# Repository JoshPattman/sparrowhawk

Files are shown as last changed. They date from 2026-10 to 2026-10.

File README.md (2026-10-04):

# Sparrowhawk

A sub-250g RC flying wing that is as quick to build as possible: two 3D printed parts for the fuselage, and one simple shape cut from foamboard for the wing.

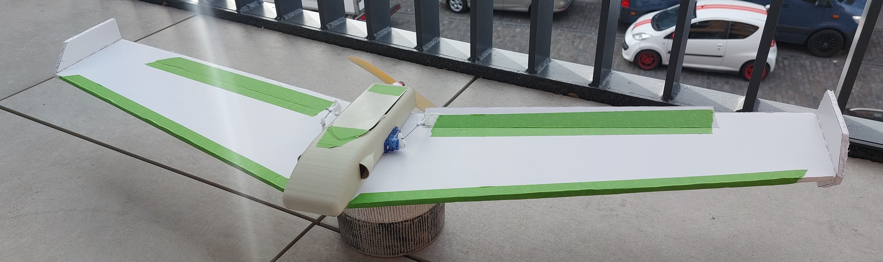
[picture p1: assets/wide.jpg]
Sparrowhawk


Sparrowhawk is designed to maximise wingspan, build speed, and robustness while staying under 250g.

- **Wingspan:** 841mm (the full width of an A1 sheet)
- **All-up weight:** 242g as built, including a 3S 850mAh battery
- **Flight time:** 15-20 minutes on a 3S 850mAh battery
- **Aerobatics:** flips and rolls with ease
- **Build:** two printed parts and one sheet of A1 foamboard, which is enough for two wings

## Plans

The plans include the full parts list, the foamboard cutting template for the wing and wingtips, and the CG position. All dimensions are in mm, and the sheet is A1.

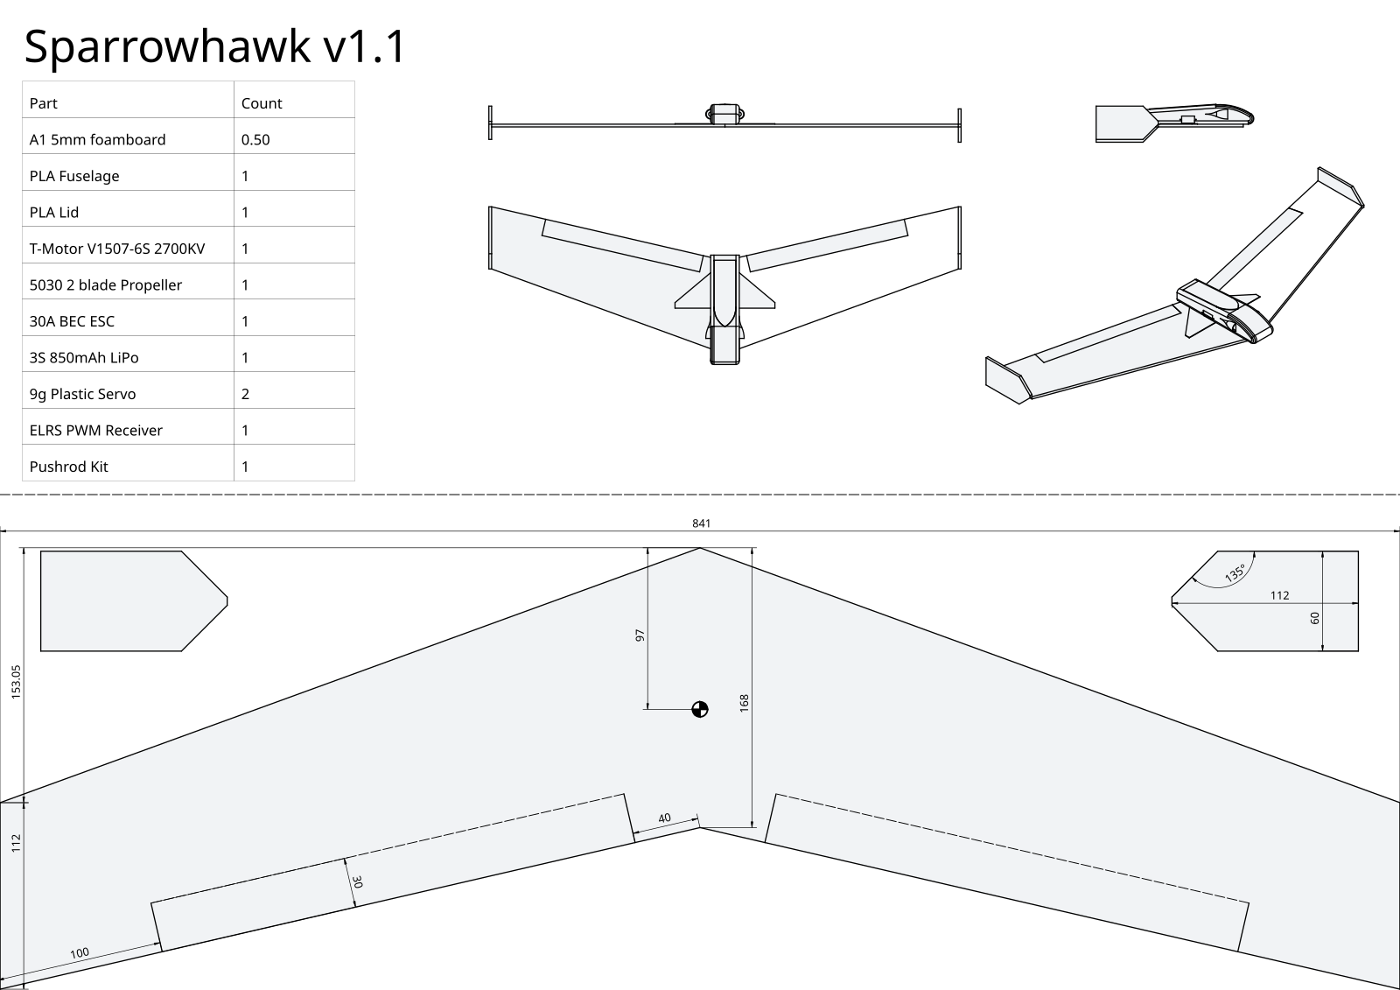
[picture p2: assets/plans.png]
Plans


The full-size A1 plans are in [`plans/sparrowhawk_Plans.svg`](plans/sparrowhawk_Plans.svg).

## Build

1. Print the [fuselage](stl/sparrowhawk-Fuselage.stl) and [lid](stl/sparrowhawk-Lid.stl).
2. Cut one wing and two wingtips from foamboard using the plans.
3. Cut the elevons free and hinge them back on with tape (also leave a layer of paper and bevel them).
4. Attach the wingtips to the ends of the wing with glue gun.
5. Fit the motor, ESC, receiver, and servos into the fuselage, then attach the fuselage to the wing.
6. Connect the servos to the elevons with the pushrods and control horns.
7. Set up elevon mixing on your transmitter.

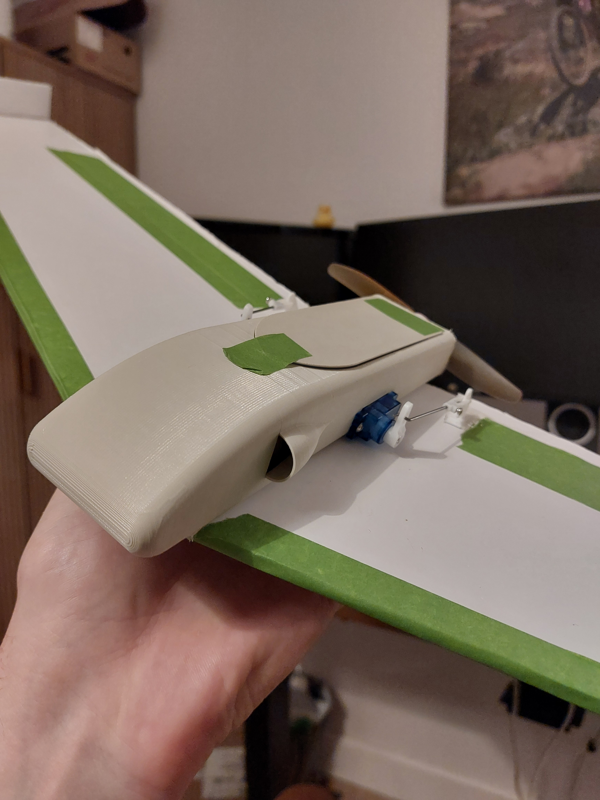
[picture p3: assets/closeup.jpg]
Close-up of the fuselage and servo linkage


## CAD

The full model is in [`sparrowhawk.FCStd`](sparrowhawk.FCStd), which opens in [FreeCAD](https://www.freecad.org/).

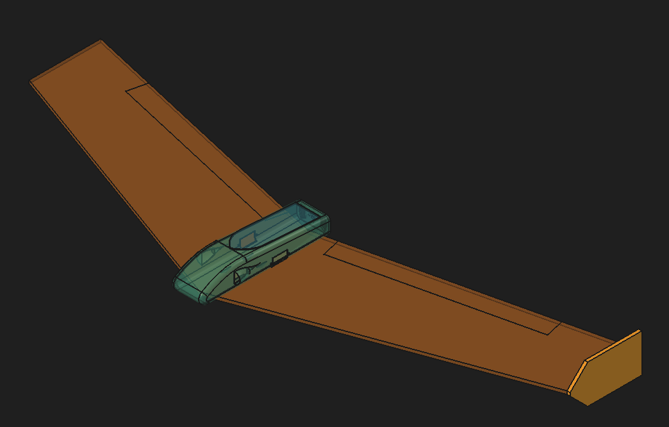
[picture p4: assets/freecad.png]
FreeCAD model


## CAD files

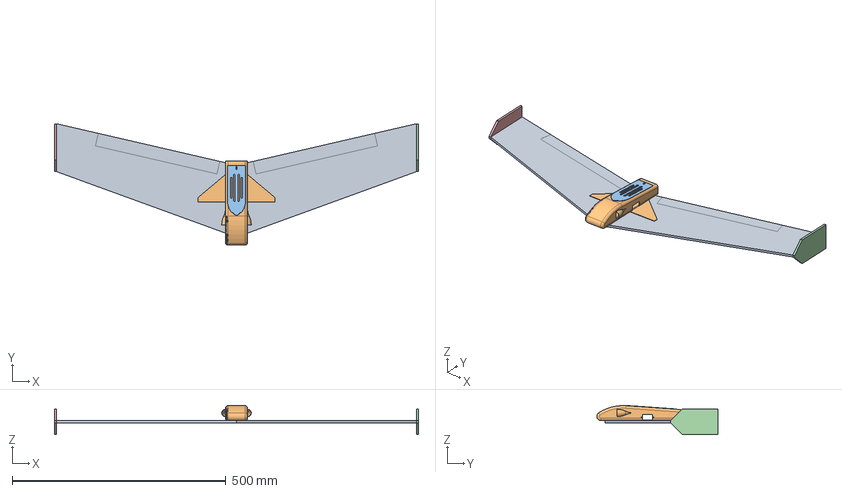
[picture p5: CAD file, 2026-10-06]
sparrowhawk.FCStd
851.0 x 284.0 x 68.1 mm
Wing
Fuselage
Lid
Wingtip
OtherWingtip
Latch

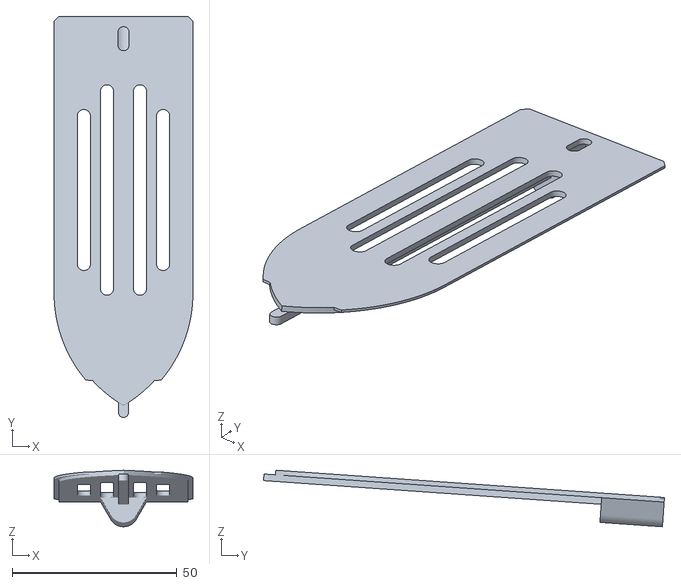
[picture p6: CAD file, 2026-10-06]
stl/sparrowhawk-Lid.stl
42.1 x 121.5 x 17.1

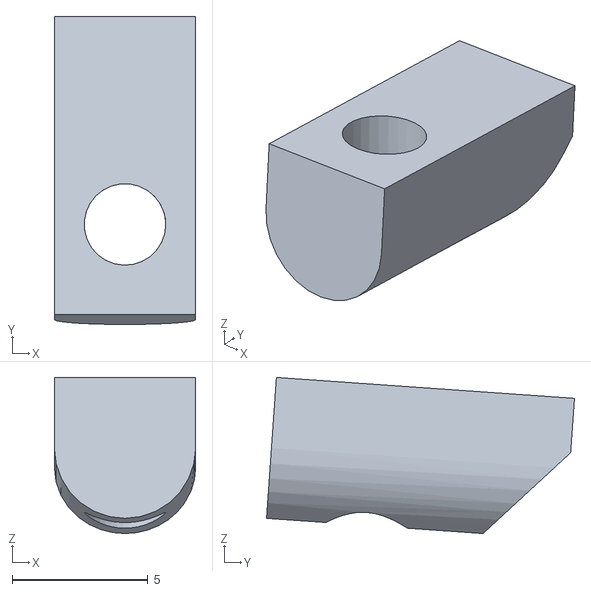
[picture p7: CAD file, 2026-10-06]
stl/sparrowhawk-Latch.stl
5.20 x 11.3 x 5.75

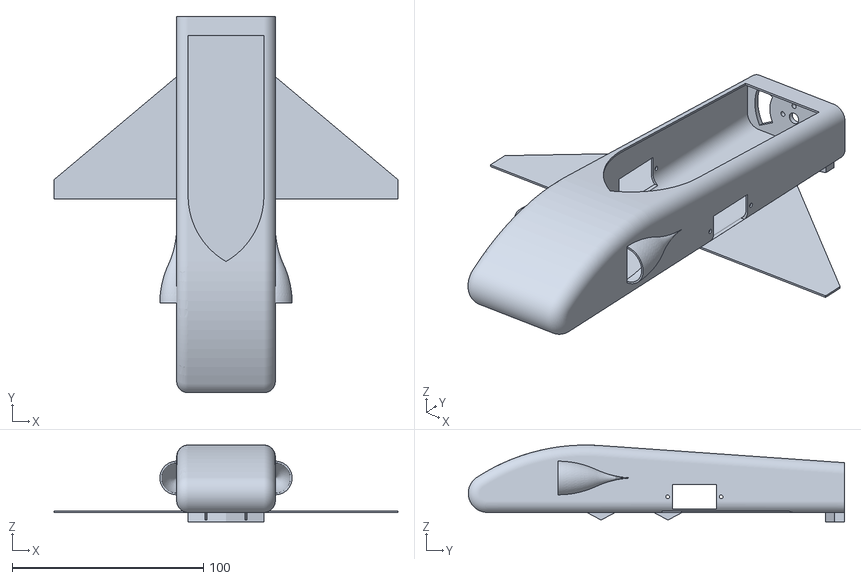
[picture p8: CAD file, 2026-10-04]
stl/sparrowhawk-Fuselage.stl
180.0 x 197.0 x 40.2

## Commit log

2026-10-03 Add initial files
    [sparrowhawk-Fuselage.stl, sparrowhawk-Lid.stl, sparrowhawk.FCStd]
2026-10-03 Add fuselage improvements
    [sparrowhawk-Fuselage.stl, sparrowhawk.FCStd]
2026-10-03 Add fuselage shorter
    [sparrowhawk-Fuselage.stl, sparrowhawk.FCStd]
2026-10-03 Add CG
    [sparrowhawk.FCStd]
2026-10-04 Update plans
    [sparrowhawk.FCStd]
2026-10-04 Make half cuts a dashed line on plans
    [sparrowhawk-Fuselage.stl, sparrowhawk-Lid.stl, sparrowhawk.FCStd]
2026-10-06 Add latched lid
    [sparrowhawk-Latch.stl, sparrowhawk-Lid.stl, sparrowhawk.FCStd]
